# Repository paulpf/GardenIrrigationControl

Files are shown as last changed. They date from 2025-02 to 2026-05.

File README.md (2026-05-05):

# GardenIrrigationControl

> Das Projekt befindet sich noch im Aufbau.

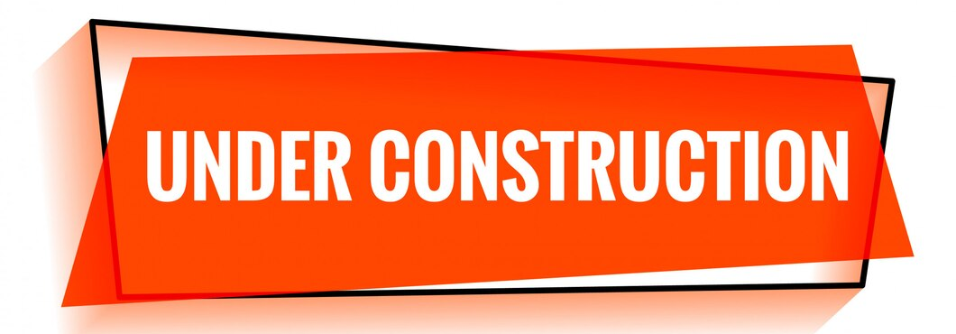
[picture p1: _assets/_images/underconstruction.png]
Projekt im Aufbau


## Inhaltsverzeichnis

- [Projektziel](#projektziel)
- [Anforderungen](#anforderungen)
- [Entwicklungsumgebung](#entwicklungsumgebung)
- [Hardware](#hardware)
  - [Stueckliste](#stueckliste)
  - [ESP32 Dev Kit C V4](#esp32-dev-kit-c-v4)
  - [SSR-Relaismodul](#ssr-relaismodul)
  - [Hunter PGV-101 Ventile](#hunter-pgv-101-ventile)
- [Verschaltung](#verschaltung)
  - [Systemuebersicht](#systemuebersicht)
  - [Steckplatinenansicht](#steckplatinenansicht)
  - [Spannungsversorgung](#spannungsversorgung)
  - [SSR-Modul und Ventile](#ssr-modul-und-ventile)
  - [Taster](#taster)
  - [Status-LED je Zone](#status-led-je-zone)
  - [Wasserstandssensor mit Shunt-Widerstand](#wasserstandssensor-mit-shunt-widerstand)
- [GPIO-Belegung](#gpio-belegung)
  - [Zonenbelegung](#zonenbelegung)
  - [Reservierte und gemiedene Pins](#reservierte-und-gemiedene-pins)
- [Hardware-Risiken und Hinweise](#hardware-risiken-und-hinweise)
- [Hardwaretests](#hardwaretests)
- [OTA-Updates](#ota-updates)

## Projektziel

GardenIrrigationControl steuert eine Gartenbewaesserung mit einem ESP32, einem
SSR-Relaismodul und 24-V-AC-Magnetventilen. Die Bewaesserungszonen koennen per
MQTT, Web-/Netzwerklogik oder ueber physische Taster geschaltet werden. Zusaetzlich
kann der Fuellstand einer Zisterne ueber einen 4-20-mA-Sensor erfasst werden.

## Anforderungen

Das System soll:

- ueber eine Web- bzw. Netzwerk-Schnittstelle steuerbar sein
- Befehle und Statusdaten per MQTT verarbeiten
- physische Taster fuer manuelle Bewaesserung unterstuetzen
- auch ohne WLAN manuell bedienbar bleiben
- den Wasserstand einer Zisterne ueber einen kapazitiven 4-20-mA-Sensor messen
- Over-The-Air-Updates fuer die Firmware unterstuetzen

## Entwicklungsumgebung

Dieses Projekt erwartet Secret- und Konfigurations-Header ausserhalb des
Repositorys.

Setup-Skript ausfuehren:

```powershell
powershell -ExecutionPolicy Bypass -File .\scripts\setup_secrets.ps1
```

Oder unter Windows:

```bat
scripts\setup_secrets.bat
```

Das Skript erstellt oder aktualisiert diese Dateien einen Ordner oberhalb des
Repository-Roots:

- `_secrets/WifiSecret.h`
- `_secrets/MqttSecret.h`
- `_secrets/OtaSecret.h`
- `_config/MqttConfig.h`

Existierende Dateien werden vorher mit Zeitstempel gesichert, z. B.
`WifiSecret.h.20260503-153000.bak`.

## Hardware

### Stueckliste

| Menge | Bauteil | Modell / Wert | Zweck / Hinweis |
| ---: | --- | --- | --- |
| 1 | Microcontroller | ESP32 Dev Kit C V4, AZ-Delivery | Steuerung, WLAN, MQTT, OTA |
| 1 | Relaismodul | 8-Kanal SSR 5 V DC, Low-Level-Trigger | Schaltet Zone 1 bis 8 |
| 1 | Zusatzrelais | 24 V AC geeignet, Low-Level-Trigger | Schaltet Zone 9 / Drainage |
| 9 | Magnetventil | Hunter PGV-101 | 24-V-AC-Bewaesserungsventile |
| 9 | Drucktaster | NO, normally open | Manuelle Zonensteuerung |
| 1 | Trafo | 24 V AC, ausreichend dimensioniert | Versorgung der Magnetventile |
| 1 | Hutschienennetzteil | Mean Well HDR-15-5, 5 V DC | Versorgung von ESP32 und SSR-Steuerseite |
| 1 | 4-20-mA-Sensor | kapazitiver Fuellstandssensor | Zisternenfuellstand |
| 1 | Shunt-Widerstand | ca. 165 Ohm | Wandelt 4-20 mA auf ADC-Spannung |
| 3 | Pull-down-Widerstand | 10 kOhm | Fuer GPIO 34, 35 und 39 |
| optional 9 | Pull-up-Widerstand | 10 kOhm | Je SSR-Eingang nach 3V3, wenn noetig |
| optional 9 | Status-LED | 5 mm, Farbe nach Wunsch | Anzeige des echten 24-V-AC-Ausgangs |
| optional 9 | LED-Vorwiderstand | 10 kOhm / 0,5 W | Strombegrenzung fuer 24 V AC |
| optional 9 | Schutzdiode | 1N4148 oder 1N4007 | Antiparallel zur Status-LED |
| optional 9 | LED-Halter | 5-mm-Frontclip | Montage in der Gehaeusefront |
| optional | Schrumpfschlauch / Litze | 0,14-0,25 mm2 | Isolation und Verdrahtung |

### ESP32 Dev Kit C V4

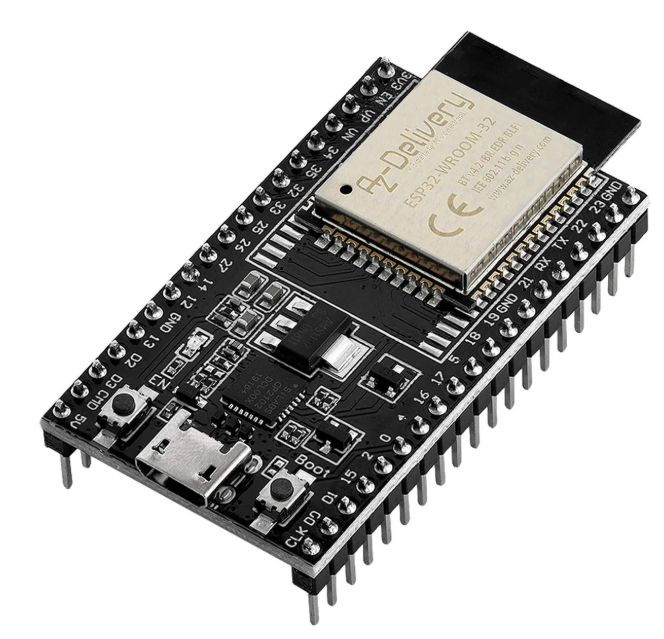
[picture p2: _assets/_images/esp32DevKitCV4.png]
ESP32 Dev Kit C V4


- Produkt: ESP32 Dev Kit C V4
- Anbieter: AZ-Delivery
- Versorgung: 5 V ueber USB oder VIN/5V-Pin, intern 3,3 V Logikpegel

Pinout:

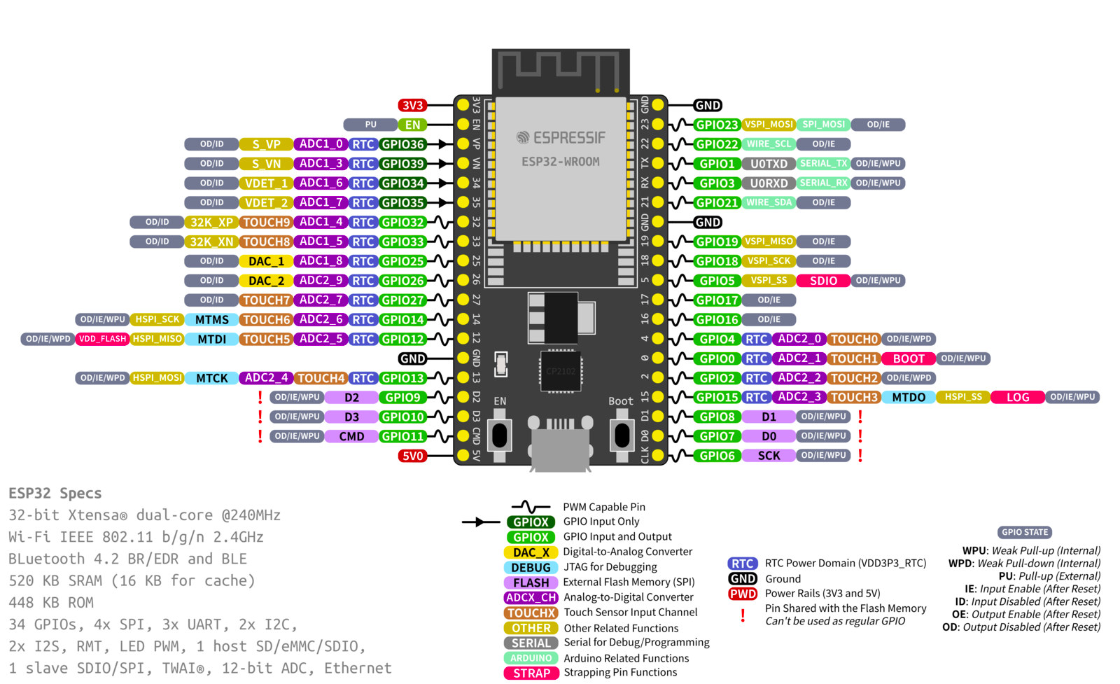
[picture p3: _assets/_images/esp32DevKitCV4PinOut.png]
ESP32 Pinout


Quelle: [ESP32 Pinout](https://www.cnx-software.com/wp-content/uploads/2022/09/ESP32-DevkitC-V4-pinout-diagram.jpg)

### SSR-Relaismodul

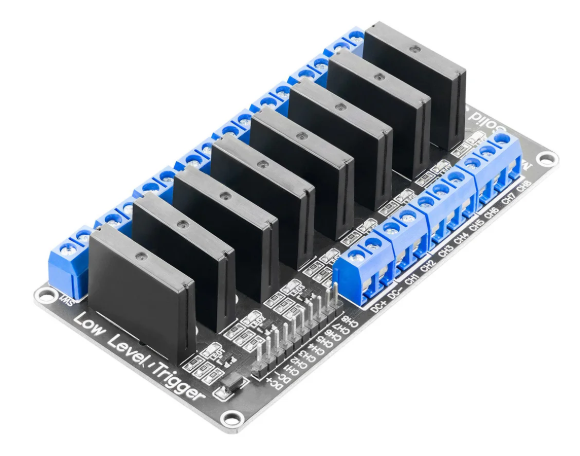
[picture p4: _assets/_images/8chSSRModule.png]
8-Kanal SSR-Modul


- Produkt: 8-Kanal Solid State Relais, 5 V DC, Low-Level-Trigger
- Anbieter: AZ-Delivery
- Steuerseite: 5 V DC
- Lastseite: 24 V AC fuer Magnetventile

Wichtig: LOW am SSR-Eingang aktiviert den Kanal, HIGH deaktiviert ihn.

### Hunter PGV-101 Ventile

- 9 Magnetventile fuer die Bewaesserungszonen
- Betrieb mit 24 V AC
- Zone 9 ist als Zusatz- bzw. Drainagezone vorgesehen

## Verschaltung

### Systemuebersicht

```mermaid
graph TD
    subgraph PSU ["Stromversorgung"]
        V24["24 V AC Trafo"]
        V5["5 V DC Netzteil\nMean Well HDR-15-5"]
    end

    subgraph CTRL ["Steuerung"]
        ESP32["ESP32 Dev Kit C V4"]
    end

    subgraph IO ["Eingabe"]
        BTN["9x Drucktaster\nNO, gegen 3V3"]
        SENSOR["4-20-mA-Fuellstandssensor\nueber Shunt an GPIO36 / VP"]
    end

    subgraph REL ["Relais"]
        SSR["8-Kanal SSR Modul\n+ 1 Zusatzrelais\nLOW = aktiv"]
    end

    subgraph VALVES ["Bewaesserungsventile"]
        V1["Zone 1"]
        V2["Zone 2"]
        V3["Zone 3"]
        V4["Zone 4"]
        V5X["Zone 5"]
        V6["Zone 6"]
        V7["Zone 7"]
        V8["Zone 8"]
        V9["Zone 9 Drainage"]
    end

    V5 -->|"5 V DC"| ESP32
    V5 -->|"5 V DC Steuerseite"| SSR
    ESP32 -->|"GPIO 16,17,18,19,21,22,23,25,26"| SSR
    BTN -->|"GPIO 4,13,14,27,32,33,34,35,39"| ESP32
    SENSOR -->|"ADC GPIO36 / VP"| ESP32
    V24 -->|"24 V AC gemeinsame Leitung"| SSR
    SSR -->|"24 V AC geschaltet"| V1 & V2 & V3 & V4 & V5X & V6 & V7 & V8 & V9
    V24 -->|"24 V AC Rueckleitung"| V1 & V2 & V3 & V4 & V5X & V6 & V7 & V8 & V9
```

Fallback-Grafik ohne Mermaid-Renderer:
[docs/system_overview.svg](docs/system_overview.svg)

### Steckplatinenansicht

<figure>
  Fritzing-Steckplatinenansicht der GardenIrrigationControl-Verdrahtung
  <figcaption>Steckplatinenansicht der ESP32-, SSR-, Taster- und Ventilverdrahtung.</figcaption>
</figure>

Die Grafik ist aus der Fritzing-Datei `_assets/IrrigationCircuit.fzz`
abgeleitet und dient als visuelle Aufbauhilfe zur nachfolgenden
Verdrahtungsbeschreibung.

### Spannungsversorgung

```text
Steckdose 230 V AC
|
+-- 24 V AC Trafo
|   +-- L1 -> SSR COM / gemeinsame Eingangsleitung
|   +-- L2 -> gemeinsame Rueckleitung aller Ventile
|
+-- 5 V DC Netzteil Mean Well HDR-15-5
    +-- +V -> ESP32 VIN/5V
    +-- 5 V -> SSR VCC / Steuerseite
    +-- -V/GND -> ESP32 GND und SSR GND
```

Wichtig: ESP32-GND und SSR-Steuer-GND muessen verbunden sein. Die 24-V-AC-Seite
bleibt galvanisch von der Steuerseite getrennt.

Das ESP32 Dev Kit C V4 wird mit 5 V am VIN/5V-Pin versorgt. Der
Spannungsregler auf dem Devboard erzeugt daraus die interne 3,3-V-Versorgung
fuer den ESP32 und kleine 3,3-V-Verbraucher. Niemals 5 V direkt an einen
3V3-Pin anschliessen. Bei gleichzeitiger USB-Verbindung zum PC pruefen, ob das
konkrete Devboard eine Rueckspeisung zwischen externer 5-V-Versorgung und USB
verhindert.

### SSR-Modul und Ventile

Verdrahtung je Zone:

```text
ESP32 GPIO, z. B. GPIO16 -----------------> SSR IN1
ESP32 GND --------------------------------> SSR GND
5 V DC -----------------------------------> SSR VCC

24 V AC Trafo L1 -------------------------> SSR COM
SSR NO / Ausgang -------------------------> Ventil Zone 1, Klemme A
24 V AC Trafo L2 -------------------------> Ventil Zone 1, Klemme B
```

Vereinfachter Stromkreis:

```text
24 V AC L1 -- SSR COM -- SSR Ausgang -- Ventil -- 24 V AC L2
```

Bei LOW am Relais-GPIO schliesst der SSR-Kanal und das Ventil oeffnet. Bei HIGH
ist der Kanal aus und das Ventil geschlossen. Die Firmware setzt die Relaispins
beim Start zuerst auf HIGH und schaltet sie danach als OUTPUT, damit die
Ausgaenge moeglichst inaktiv starten.

### Taster

Jeder Taster ist als normally-open-Taster gegen 3V3 verdrahtet:

```text
3V3 ---- Taster ---- ESP32 GPIO
GND ---- Pull-down -- ESP32 GPIO
```

Fuer GPIO 4, 13, 14, 27, 32 und 33 wird der interne Pull-down des ESP32 genutzt.
GPIO 34, 35 und 39 sind input-only und besitzen keinen internen Pull-down; diese
drei Taster benoetigen jeweils einen externen 10-kOhm-Pull-down nach GND.

### Status-LED je Zone

Wenn eine LED den realen Schaltzustand anzeigen soll, wird sie parallel zum
jeweiligen 24-V-AC-Ventilausgang angeschlossen. Dadurch zeigt sie den tatsaechlich
geschalteten Ausgang, nicht nur den GPIO-Zustand.

<figure>
  24 V AC Status-LED mit 10 kOhm Vorwiderstand und antiparalleler Schutzdiode
  <figcaption>24 V AC Status-LED mit Vorwiderstand R1 und antiparalleler Schutzdiode D1.</figcaption>
</figure>

Stueckliste pro LED:

| Menge | Bauteil | Wert / Typ | Hinweis |
| ---: | --- | --- | --- |
| 1 | LED | 5 mm, Farbe nach Wunsch | Lange Anschlussfahne ist meist Anode |
| 1 | Widerstand R1 | 10 kOhm / 0,5 W | 0,25 W reicht rechnerisch, 0,5 W ist robuster |
| 1 | Diode D1 | 1N4148 oder 1N4007 | Ring / Strich markiert die Kathode |
| 1 | LED-Halter | 5-mm-Frontclip | Passend zur Gehaeusefront |
| 1 | Schrumpfschlauch | passend | Alle blanken Kontakte isolieren |
| optional | Litze | 0,14-0,25 mm2 | Anschluss an Klemme oder Platine |

Verdrahtung:

1. R1 in Reihe zur LED einbauen.
2. D1 direkt antiparallel zur LED anschliessen.
3. Dioden-Kathode, also Ring / Strich, an die LED-Anode anschliessen.
4. Dioden-Anode an die LED-Kathode anschliessen.
5. LED-Schaltung parallel zum jeweiligen 24-V-AC-Ventilausgang anschliessen.
6. Alle blanken Anschluesse mit Schrumpfschlauch isolieren.

Dimensionierung:

```text
24 V AC * 1,414 = ca. 34 V Spitzenspannung
I = (34 V - ca. 2 V) / 10000 Ohm = ca. 3,2 mA Spitzenstrom
P = 24 V * 24 V / 10000 Ohm = ca. 0,058 W
```

Ein 0,25-W-Widerstand reicht rechnerisch aus. Ein 0,5-W-Widerstand ist
empfehlenswert, weil er kuehler bleibt, mechanisch robuster ist und mehr Reserve
im Gehaeuse bietet.

### Wasserstandssensor mit Shunt-Widerstand

Der Wasserstandssensor liefert ein 4-20-mA-Signal. Der ESP32 misst aber keine
Stroeme direkt, sondern eine Spannung am ADC. Deshalb wird der Sensorstrom durch
einen Shunt-Widerstand gefuehrt. Die Spannung ueber diesem Widerstand liegt am
ADC-Pin GPIO36 / VP an.

<figure>
  4-20 mA Wasserstandssensor mit 165 Ohm Shunt-Widerstand an ESP32 GPIO36 VP
  <figcaption>4-20-mA-Sensor mit 165-Ohm-Shunt am ADC-Eingang GPIO36 / VP.</figcaption>
</figure>

Stueckliste fuer den Messeingang:

| Menge | Bauteil | Wert / Typ | Hinweis |
| ---: | --- | --- | --- |
| 1 | Fuellstandssensor | 4-20 mA, kapazitiv | Versorgung laut Sensor-Datenblatt |
| 1 | Shunt-Widerstand | ca. 165 Ohm | Wandelt 4-20 mA in ca. 0,66-3,3 V |
| optional 1 | Serienwiderstand | 1 kOhm | Zusaetzlicher Schutz vor dem ADC-Pin |
| optional 1 | Kondensator | 100 nF | Gegen GND am ADC-Knoten zur Glaettung |

Verdrahtung bei einem typischen 2-Draht-4-20-mA-Sensor:

```text
DC Versorgung + ---- Sensor + 
Sensor - / Iout ---- ADC-Knoten ---- GPIO36 / VP
ADC-Knoten --------- Rshunt 165 Ohm ---- GND
DC Versorgung GND ---------------------- GND
ESP32 GND ------------------------------ GND
```

Der ADC-Knoten ist die Verbindung aus Sensor-Ausgang, Shunt-Widerstand und
GPIO36 / VP. Der Shunt liegt von diesem Knoten nach GND. ESP32-GND und die
Masse der Sensorspeisung muessen verbunden sein, damit der ADC eine definierte
Bezugsspannung hat.

Dimensionierung:

```text
U = I * R
Umin = 0,004 A * 165 Ohm = 0,66 V
Umax = 0,020 A * 165 Ohm = 3,30 V
Pmax = I^2 * R = 0,020 A * 0,020 A * 165 Ohm = 0,066 W
```

Ein 0,25-W-Widerstand reicht elektrisch aus; 0,5 W ist mechanisch robuster. Der
ADC-Pin GPIO36 / VP darf maximal 3,3 V sehen. Daher darf die Sensorversorgung
niemals direkt auf GPIO36 gelegt werden, und 24 V AC gehoert ausschliesslich auf
die Ventilseite, nicht auf den Messeingang.

Firmware-Bezug:

| Firmware-Wert | Bedeutung |
| --- | --- |
| `WATER_LEVEL_SENSOR_PIN = 36` | ADC-Eingang GPIO36 / VP |
| `WATER_LEVEL_ADC_MIN = 820` | ca. 0,66 V bei 4 mA |
| `WATER_LEVEL_ADC_MAX = 4095` | ca. 3,3 V bei 20 mA |

## GPIO-Belegung

### Zonenbelegung

Diese Tabelle entspricht der Firmware in `src/config/config.h`.

| Zone | Funktion | Taster-GPIO | Taster-Board-Label | Relais-GPIO | Relais-Board-Label | SSR-Kanal | Hinweis |
| --- | --- | ---: | --- | ---: | --- | --- | --- |
| 1 | Bewaesserung | 4 | D4 | 16 | RX2 | IN1 | interner Pull-down |
| 2 | Bewaesserung | 13 | D13 | 17 | TX2 | IN2 | interner Pull-down |
| 3 | Bewaesserung | 14 | D14 | 18 | D18 | IN3 | interner Pull-down |
| 4 | Bewaesserung | 27 | D27 | 19 | D19 | IN4 | interner Pull-down |
| 5 | Bewaesserung | 32 | D32 | 21 | D21 | IN5 | interner Pull-down |
| 6 | Bewaesserung | 33 | D33 | 22 | D22 | IN6 | interner Pull-down |
| 7 | Bewaesserung | 34 | D34 | 23 | D23 | IN7 | externer 10-kOhm-Pull-down noetig |
| 8 | Bewaesserung | 35 | D35 | 25 | D25 | IN8 | externer 10-kOhm-Pull-down noetig |
| 9 | Drainage / Zusatzventil | 39 | VN | 26 | D26 | Zusatzrelais | externer 10-kOhm-Pull-down noetig |

Weitere Sensorik:

| Funktion | GPIO | Board-Label | Hinweis |
| --- | ---: | --- | --- |
| Wasserstand 4-20 mA | 36 | VP | ADC1, ueber Shunt-Widerstand |

ADC-Vorgaben in der Firmware:

| Wert | Bedeutung |
| --- | --- |
| `WATER_LEVEL_ADC_MIN = 820` | ca. 0,66 V bei 4 mA an 165 Ohm |
| `WATER_LEVEL_ADC_MAX = 4095` | ca. 3,3 V bei 20 mA an 165 Ohm |

### Reservierte und gemiedene Pins

| GPIO | Grund |
| --- | --- |
| 0, 2, 5, 12, 15 | Strapping-Pins, bleiben frei |
| 1, 3 | UART TX/RX fuer Serial / OTA |
| 6 bis 11 | ESP32-Flash, nicht verwenden |
| 34, 35, 39 | input-only, kein interner Pull-down |
| 36 / VP | input-only, fuer Wasserstandssensor reserviert |

## Hardware-Risiken und Hinweise

| Problem | Status / Risiko | Empfehlung |
| --- | --- | --- |
| 8-Kanal-SSR reicht nur fuer 8 Zonen | geloest | Zone 9 nutzt ein separates Zusatzrelais |
| LOW-active SSR-Eingaenge koennen beim Reset floaten | niedrig | Firmware startet Relaispins inaktiv; optional 10-kOhm-Pull-up je SSR-Eingang pruefen |
| Hunter PGV-101 benoetigt 24 V AC | geloest | 24-V-AC-Trafo und AC-faehige Relais-/SSR-Lastseite verwenden |
| Kurzschluss / Ueberstrom auf Ventilseite | mittel | Feinsicherung 1 A pro Ventilkreis oder Gruppenabsicherung vorsehen |
| GPIO 34, 35 und 39 ohne Pull-down | relevant | Je Taster einen externen 10-kOhm-Pull-down nach GND verbauen |

## Hardwaretests

Der Test `test_embedded_esp32_gpio_io` laeuft direkt auf dem per USB
angeschlossenen ESP32 und prueft die GPIOs:

- Ausgangs-GPIOs werden kurz auf LOW und HIGH gesetzt und per `digitalRead()`
  zurueckgelesen.
- Eingangs-GPIOs muessen im Ruhezustand LOW sein.
- Fuer jeden Eingang fordert der Test im Terminal auf, den Eingang kurz auf HIGH
  zu bringen und danach wieder loszulassen.

Sicherheit vor dem Test: Der Test schaltet die Ausgangs-GPIOs kurz auf LOW. Wenn
das SSR-Modul angeschlossen ist, kann dadurch ein Relais aktivieren. Fuer einen
reinen ESP32-Test daher SSR-Modul oder Ventilversorgung trennen.

Ausfuehren:

```powershell
pio test -e az-delivery-devkit-v4-usb -f test_embedded_esp32_gpio_io
```

Falls `pio` in der aktuellen Shell nicht im `PATH` liegt:

```powershell
C:\Users\paul\.platformio\penv\Scripts\pio.exe test -e az-delivery-devkit-v4-usb -f test_embedded_esp32_gpio_io
```

Ein erfolgreicher Lauf endet mit `PASSED`.

## OTA-Updates

Dieses Projekt unterstuetzt OTA-Updates, damit neue Firmware ohne direkten
USB-Zugriff auf den ESP32 geladen werden kann.

1. IP-Adresse des ESP32 ermitteln, z. B. im Router oder ueber den Serial Monitor.
2. In `platformio.ini` im Environment fuer OTA den Upload-Port setzen:

   ```ini
   upload_port = 192.168.x.x
   ```

3. In `OtaSecret.h` das OTA-Passwort setzen:

   ```cpp
   #define OTA_PASSWORD "YourSecurePassword123"
   ```

4. Firmware hochladen:

   ```bash
   pio run -e esp32dev-ota -t upload
   ```

Bei Timeout-Problemen kann in `platformio.ini` ein groesserer Timeout gesetzt
werden:

```ini
upload_flags =
  --port=3232
  --timeout=30
```

Waehrend eines OTA-Updates pausiert das System Bewaesserungsoperationen, damit
das Update stabil durchlaufen kann.

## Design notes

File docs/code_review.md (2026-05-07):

# Code Review

Datum: 2026-05-07
Repository: GardenIrrigationControl

## Kurzfazit

Das Projekt ist fuer ein Embedded-/ESP32-Projekt bereits gut strukturiert. Die
Trennung in `app`, `domain`, `infrastructure`, `services`, `contracts` und
Tests ist ein solider Anfang. Besonders positiv sind die Native-Tests, die
Dependency-Injection-Ansaetze und die Dokumentation der Hardware.

Die wichtigsten Verbesserungsfelder liegen bei langlebiger ESP32-Stabilitaet,
MQTT-Verantwortlichkeiten, echter Produktionslogik in Tests und dem Umgang mit
noch unfertigen Features.

## Testergebnis

Native-Testlauf:

```text
pio test -e native
127 test cases: 127 succeeded
```

Hinweis: Der erste Testlauf im Sandbox-Kontext scheiterte an PlatformIO-
Berechtigungen unter `C:\Users\ppfei\.platformio`. Nach Ausfuehrung ausserhalb
der Sandbox liefen alle Native-Tests erfolgreich.

## Findings

### 1. Geplante Bewaesserung ist noch nicht funktionsfaehig

Datei: `src/domain/scheduled_irrigation.cpp`

`ScheduledIrrigation::isScheduleTimeMatch()` gibt aktuell immer `false`
zurueck. Dadurch kann geplante Bewaesserung nie ausloesen, obwohl Klasse und
Tests bereits wie ein vorhandenes Feature wirken.

Empfehlung:

- Entweder das Feature klar als unfertig kennzeichnen und nicht als fertige
  Funktion behandeln.
- Oder einen echten Zeitprovider/NTP-Provider integrieren und
  `isScheduleTimeMatch()` produktionsreif implementieren.
- Tests sollten danach echte Trigger-Faelle gegen Produktionslogik abdecken.

### 2. MQTT-Payloads werden still auf 255 Zeichen gekuerzt

Datei: `src/infrastructure/mqttmanager.cpp`

In `instanceMqttCallback()` wird der Payload in einen festen Buffer kopiert.
Payloads ueber 255 Zeichen werden abgeschnitten, ohne dass der Command
abgelehnt oder als fehlerhaft markiert wird.

Fuer aktuelle Bool- und Duration-Kommandos ist das meist unkritisch. Sobald
spaeter JSON-Kommandos, Schedule-Konfigurationen oder komplexere Payloads per
MQTT kommen, kann daraus aber ein schwer zu findender Fehler entstehen.

Empfehlung:

- Ueberlange Payloads explizit erkennen.
- Command mit Logmeldung ablehnen statt gekuerzt weiterzuverarbeiten.
- Fuer kuenftige JSON-Kommandos feste Maximalgroessen definieren.

### 3. Viele temporaere `String`-Objekte im MQTT-Hotpath

Dateien:

- `src/infrastructure/mqttmanager.cpp`
- `src/infrastructure/mqttmanager.h`

Der MQTT-Callback erzeugt viele temporaere `String`-Objekte fuer Topic-Vergleiche,
Topic-Erzeugung, Logs und Publish-Payloads. Auf ESP32-Systemen kann das bei
langer Laufzeit Heap-Fragmentierung beguenstigen.

Empfehlung:

- MQTT-Topics beim Setup einmal in feste Buffer vorberechnen.
- Eine kleine `MqttTopicRegistry` oder einen `MqttTopicBuilder` einfuehren.
- Im Callback moeglichst mit `strcmp`, Prefix-Matching und festen Buffern
  arbeiten.
- `String` in seltenen Setup-/Logpfaden tolerieren, aber nicht im Hotpath.

### 4. ISR- und Mainloop-Zugriff sind nur mit `volatile` abgesichert

Dateien:

- `src/domain/irrigation_zone.cpp`
- `src/domain/irrigation_zone.h`

`_lastDebounceTime` und `_buttonEventPending` werden aus Interrupt-Service-
Routine und Mainloop genutzt. `volatile` verhindert Optimierungen, ist aber
keine vollstaendige Synchronisation.

Empfehlung:

- ISR minimal halten und nur ein Ereignis-Flag setzen.
- Debounce-Logik vollstaendig in der Mainloop ausfuehren.
- Alternativ kritische Abschnitte fuer gemeinsam genutzte Werte verwenden.
- Ggf. einen kleinen `ButtonDebouncer` als testbare Domain-Komponente
  extrahieren.

### 5. Wasserstand-Prozentwert wird unten begrenzt, aber nicht oben

Datei: `src/domain/waterlevelmanager.cpp`

Der berechnete Prozentwert wird auf mindestens 0 begrenzt, aber nicht auf 100.
Das ist fuer Overflow-Erkennung teilweise sinnvoll, vermischt aber Anzeige- und
Diagnosewert.

Empfehlung:

- Zwei Werte unterscheiden:
  - `rawPercent` fuer Diagnose, Sensorfehler und Overflow-Erkennung.
  - `displayPercent` fuer UI/MQTT-Anzeige, begrenzt auf `0..100`.
- MQTT-Topics entsprechend klar benennen oder dokumentieren.

### 6. OTA ist als Default-Environment aktiviert

Datei: `platformio.ini`

`default_envs` enthaelt USB und OTA. Gleichzeitig steht im OTA-Environment eine
konkrete IP-Adresse sowie ein Platzhalter fuer das Auth-Flag.

Risiko:

- Versehentliche OTA-Builds oder Uploads.
- Lokale IP-Adresse im versionierten Projekt.
- Auth-Konfiguration wirkt wie ein Platzhalter, ist aber Teil der aktiven
  Projektkonfiguration.

Empfehlung:

- OTA aus `default_envs` entfernen.
- OTA-Upload nur bewusst mit `pio run -e az-delivery-devkit-v4-ota -t upload`
  starten.
- IP/Auth aus lokaler Konfiguration oder Secrets beziehen.
- Beispielwerte in eine dokumentierte Template-Datei verschieben.

## Design-Tipps

### MQTT-Verantwortlichkeiten aufteilen

`MqttManager` uebernimmt derzeit viele Aufgaben:

- MQTT-Verbindung
- Reconnect-Logik
- Topic-Erzeugung
- Command-Parsing
- Factory-Reset
- Duration-Reset
- State-Publishing
- LWT/Systemstatus

Empfohlene Aufteilung:

- `MqttConnectionManager` fuer Verbindung und Reconnect.
- `MqttTopicBuilder` oder `MqttTopicRegistry` fuer Topics.
- `IrrigationCommandHandler` fuer Zonen-Kommandos.
- `SystemCommandHandler` fuer Reset/Systembefehle.
- `MqttStatePublisher` fuer Status- und Sensor-Publishes.

Das macht die Klasse kleiner, reduziert Kopplung und erleichtert gezielte Tests.

### Domain weiter von Infrastruktur trennen

Die Richtung mit `contracts/` ist gut. Einige Domain-Klassen greifen aber noch
direkt auf Infrastruktur zu, zum Beispiel `IrrigationZone` auf
`StorageManager::getInstance()`.

Empfehlung:

- Interface wie `IZoneSettingsStore` einfuehren.
- Storage ueber Konstruktor oder Setup injizieren.
- Domain-Logik ohne NVS/Preferences testbar machen.

### Tests naeher an Produktionslogik bringen

Einige Tests kopieren Produktionslogik oder testen eher Checklisten als echtes
Verhalten. Dadurch koennen Tests gruen sein, obwohl sich die echte
Implementierung anders verhaelt.

Empfehlung:

- Reine Funktionen aus Produktionscode extrahieren und direkt testen.
- Kopierte Test-Hilfsfunktionen schrittweise entfernen.
- Checklist-/Dokumentations-Tests in echte Verhaltens-Tests umwandeln.
- Scheduled-Irrigation-Tests erst dann als Feature-Test werten, wenn die
  Zeitlogik wirklich implementiert ist.

### Einheitliche Sprache und Benennung

Im Code sind Begriffe wie `relais` und `relay` gemischt. Dazu kommen deutsche
und englische Kommentare bzw. Bezeichner.

Empfehlung:

- Code-Bezeichner einheitlich auf Englisch halten.
- Hardware-Dokumentation im README kann weiterhin Deutsch bleiben.
- Begriffe wie `durationTime` praezisieren, zum Beispiel `durationMs` oder
  `durationSeconds`.

### Konfiguration klarer schichten

Aktuell liegen Defaults, Hardware-Pins, Wasserlevel-Konfiguration, OTA-Schalter
und Timing-Werte eng zusammen.

Empfehlung:

- Hardware-Pins in `hardwareconfig`.
- Laufzeit-/Loop-Parameter in `systemconfig`.
- Sensorwerte in `waterlevelconfig`.
- MQTT-/OTA-/WiFi-Werte konsequent ueber lokale Secrets oder Templates.
- README mit einer kurzen Konfigurationsmatrix ergaenzen.

## Positives

- Gute Native-Testbasis mit erfolgreichem Testlauf.
- Klare Projektstruktur mit begonnener Schichtenarchitektur.
- Hardware-Dokumentation ist ausfuehrlich und praxisnah.
- Relais-Startzustand wird fuer LOW-active Ausgaenge bewusst abgesichert.
- MQTT-LWT und Systemstatus zeigen, dass Produktionsbetrieb mitgedacht wurde.
- Wasserstand-Logik nutzt Hysterese und trennt Sensorlesen, Transitionen und
  Publishing schon recht sauber.

## Priorisierte naechste Schritte

1. `ScheduledIrrigation` entweder fertig implementieren oder klar deaktivieren.
2. MQTT-Payload-Laengen validieren und ueberlange Nachrichten ablehnen.
3. OTA aus den Default-Environments entfernen.
4. ISR-/Button-Debounce robuster gestalten.
5. MQTT-Topic-Erzeugung aus dem Hotpath herausziehen.
6. Tests bereinigen, die Produktionslogik kopieren statt sie zu testen.
7. Storage-Abhaengigkeit aus der Domain ueber ein Interface entkoppeln.

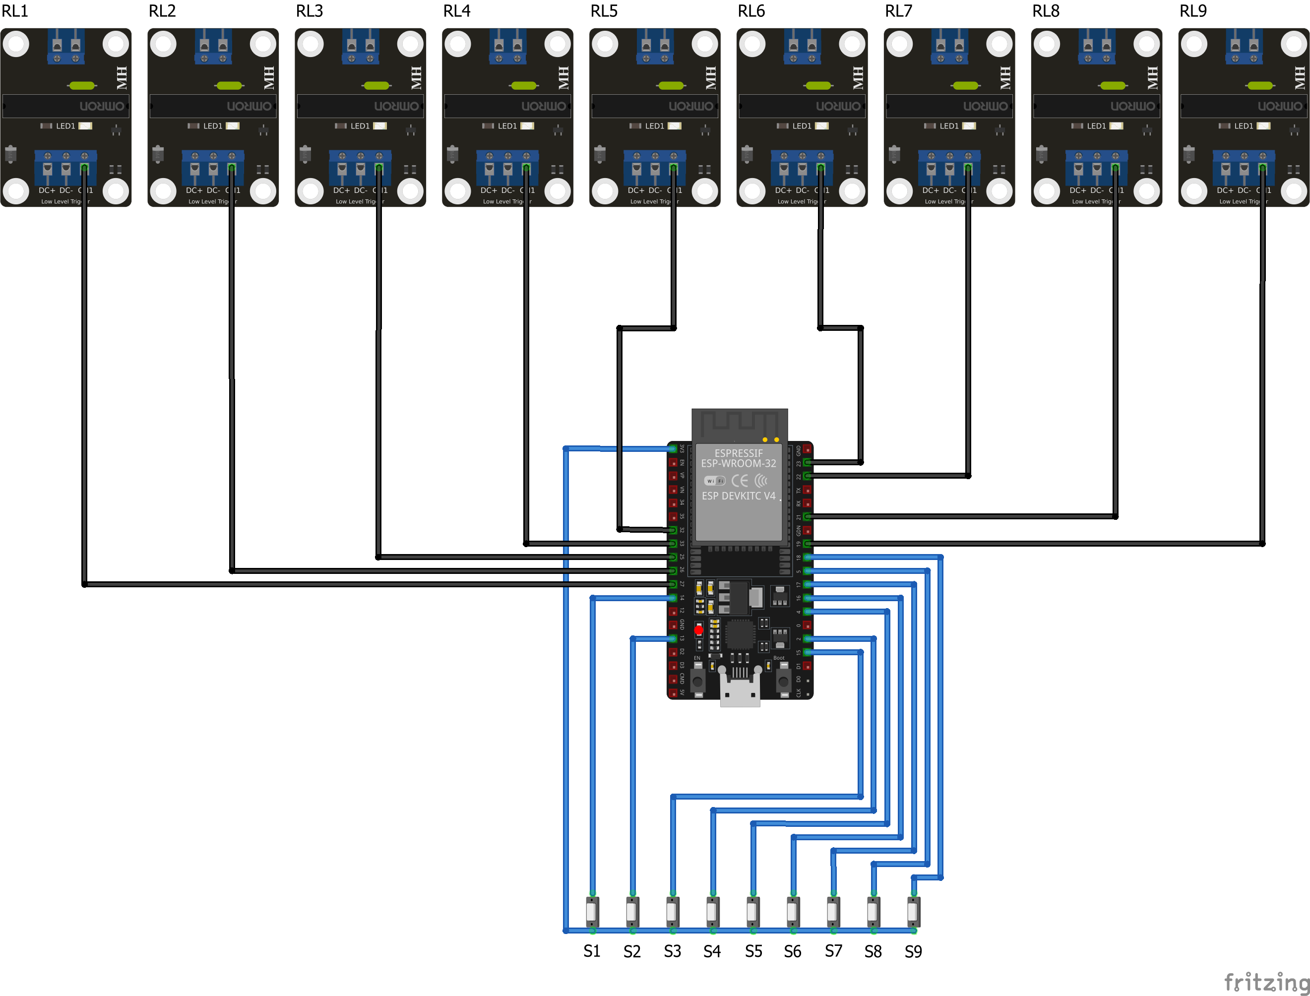
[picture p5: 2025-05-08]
_assets/_images/IrrigationCircuit_Steckplatine.png

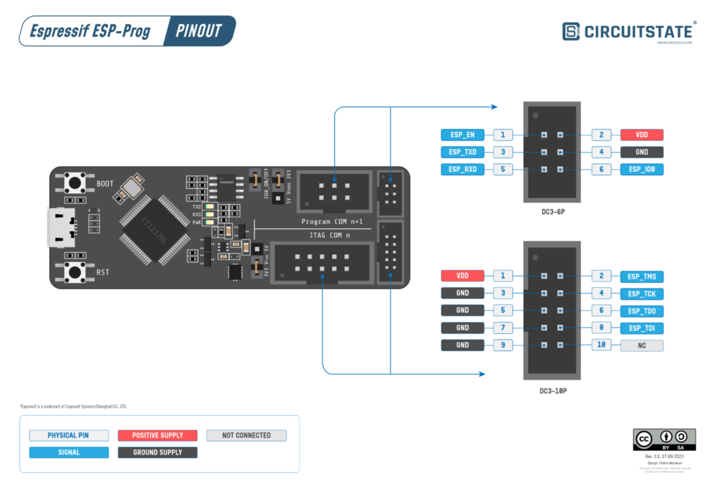
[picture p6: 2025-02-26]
_assets/_images/espprog.png

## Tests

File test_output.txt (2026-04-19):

Verbosity level can be increased via `-v, -vv, or -vvv` option
Collected 5 tests

Processing test_native_duration_formatter in native environment
--------------------------------------------------------------------------------
Building...
Testing...
test\test_native_duration_formatter\test_main.cpp:132: test_arduino_string_basic	[PASSED]
test\test_native_duration_formatter\test_main.cpp:133: test_arduino_string_int_conversion	[PASSED]
test\test_native_duration_formatter\test_main.cpp:134: test_arduino_string_concat	[PASSED]
test\test_native_duration_formatter\test_main.cpp:137: test_format_zero_returns_zeros	[PASSED]
test\test_native_duration_formatter\test_main.cpp:138: test_format_negative_returns_zeros	[PASSED]
test\test_native_duration_formatter\test_main.cpp:139: test_format_double_digit_seconds	[PASSED]
test\test_native_duration_formatter\test_main.cpp:140: test_format_exactly_one_minute	[PASSED]
test\test_native_duration_formatter\test_main.cpp:141: test_current_impl_has_seconds_suffix_bug	[PASSED]
test\test_native_duration_formatter\test_main.cpp:142: test_fixed_impl_single_digit_seconds	[PASSED]
test\test_native_duration_formatter\test_main.cpp:143: test_fixed_impl_one_second	[PASSED]
test\test_native_duration_formatter\test_main.cpp:144: test_fixed_impl_nine_seconds	[PASSED]
test\test_native_duration_formatter\test_main.cpp:145: test_fixed_impl_ten_seconds	[PASSED]
test\test_native_duration_formatter\test_main.cpp:146: test_format_large_duration	[PASSED]
------- native:test_native_duration_formatter [PASSED] Took 3.84 seconds -------

Processing test_native_irrigation_zone in native environment
--------------------------------------------------------------------------------
Building...
Testing...
test\test_native_irrigation_zone\test_main.cpp:153: test_timer_inactive_returns_zero	[PASSED]
test\test_native_irrigation_zone\test_main.cpp:154: test_timer_full_duration	[PASSED]
test\test_native_irrigation_zone\test_main.cpp:155: test_timer_half_elapsed	[PASSED]
test\test_native_irrigation_zone\test_main.cpp:156: test_timer_expired_clamped	[PASSED]
test\test_native_irrigation_zone\test_main.cpp:157: test_timer_large_elapsed_no_underflow	[PASSED]
test\test_native_irrigation_zone\test_main.cpp:158: test_timer_with_offset	[PASSED]
test\test_native_irrigation_zone\test_main.cpp:161: test_format_zero	[PASSED]
test\test_native_irrigation_zone\test_main.cpp:162: test_format_01_03	[PASSED]
test\test_native_irrigation_zone\test_main.cpp:163: test_format_05_00	[PASSED]
test\test_native_irrigation_zone\test_main.cpp:164: test_format_05_30	[PASSED]
test\test_native_irrigation_zone\test_main.cpp:165: test_format_single_digit_seconds	[PASSED]
test\test_native_irrigation_zone\test_main.cpp:166: test_format_00_59	[PASSED]
test\test_native_irrigation_zone\test_main.cpp:167: test_format_60_00	[PASSED]
test\test_native_irrigation_zone\test_main.cpp:168: test_format_negative	[PASSED]
-------- native:test_native_irrigation_zone [PASSED] Took 2.48 seconds --------

Processing test_native_mqtt_lwt in native environment
--------------------------------------------------------------------------------
Building...
Testing...
test\test_native_mqtt_lwt\test_main.cpp:261: test_lwt_offline_payload_string	[PASSED]
test\test_native_mqtt_lwt\test_main.cpp:262: test_lwt_online_payload_string	[PASSED]
test\test_native_mqtt_lwt\test_main.cpp:263: test_lwt_payloads_are_different	[PASSED]
test\test_native_mqtt_lwt\test_main.cpp:266: test_lwt_topic_format_structure	[PASSED]
test\test_native_mqtt_lwt\test_main.cpp:267: test_lwt_topic_with_different_device_names	[PASSED]
test\test_native_mqtt_lwt\test_main.cpp:270: test_lwt_qos_level_1	[PASSED]
test\test_native_mqtt_lwt\test_main.cpp:271: test_lwt_retain_flag_enabled	[PASSED]
test\test_native_mqtt_lwt\test_main.cpp:272: test_lwt_parameters_are_correct	[PASSED]
test\test_native_mqtt_lwt\test_main.cpp:275: test_lwt_prevents_stale_online_status	[PASSED]
test\test_native_mqtt_lwt\test_main.cpp:276: test_lwt_enables_failover_automation	[PASSED]
test\test_native_mqtt_lwt\test_main.cpp:277: test_lwt_improves_reliability	[PASSED]
test\test_native_mqtt_lwt\test_main.cpp:280: test_lwt_topic_buffer_no_overflow_minimal_name	[PASSED]
test\test_native_mqtt_lwt\test_main.cpp:281: test_lwt_topic_buffer_no_overflow_long_name	[PASSED]
test\test_native_mqtt_lwt\test_main.cpp:282: test_lwt_payload_strings_immutable	[PASSED]
test\test_native_mqtt_lwt\test_main.cpp:285: test_phase_5_2_implementation_checklist	[PASSED]
test\test_native_mqtt_lwt\test_main.cpp:286: test_phase_5_2_mqtt_reliability_improvement	[PASSED]
test\test_native_mqtt_lwt\test_main.cpp:287: test_phase_5_2_critical_for_production	[PASSED]
------------ native:test_native_mqtt_lwt [PASSED] Took 2.50 seconds ------------

Processing test_native_mqtt_session_manager in native environment
--------------------------------------------------------------------------------
Building...
Testing...
pio : [WinError 4551] Eine Anwendungssteuerungsrichtlinie hat diese Datei 
blockiert
In Zeile:1 Zeichen:1
+ pio test -e native 2>&1 > test_output.txt; Get-Content test_output.tx ...
+ ~~~~~~~~~~~~~~~~~~~~~~~~~~~~~~~~~~~~~~~~~
    + CategoryInfo          : NotSpecified: ([WinError 4551]...Datei blockiert 
   :String) [], RemoteException
    + FullyQualifiedErrorId : NativeCommandError
 
----- native:test_native_mqtt_session_manager [ERRORED] Took 1.54 seconds -----

Processing test_native_trace_logging in native environment
--------------------------------------------------------------------------------
Building...
Testing...
test\test_native_trace_logging\test_main.cpp:157: test_trace_level_logs_at_trace	[PASSED]
test\test_native_trace_logging\test_main.cpp:158: test_info_not_logged_when_debug_configured	[PASSED]
test\test_native_trace_logging\test_main.cpp:159: test_trace_not_logged_when_debug_configured	[PASSED]
test\test_native_trace_logging\test_main.cpp:160: test_debug_logs_at_debug_level	[PASSED]
test\test_native_trace_logging\test_main.cpp:161: test_error_logs_when_info_configured	[PASSED]
test\test_native_trace_logging\test_main.cpp:164: test_prefix_trace	[PASSED]
test\test_native_trace_logging\test_main.cpp:165: test_prefix_debug	[PASSED]
test\test_native_trace_logging\test_main.cpp:166: test_prefix_info	[PASSED]
test\test_native_trace_logging\test_main.cpp:167: test_prefix_error	[PASSED]
test\test_native_trace_logging\test_main.cpp:168: test_prefix_unknown_defaults_to_log	[PASSED]
test\test_native_trace_logging\test_main.cpp:171: test_all_levels_log_at_trace_level	[PASSED]
test\test_native_trace_logging\test_main.cpp:172: test_only_error_logs_at_error_level	[PASSED]
test\test_native_trace_logging\test_main.cpp:173: test_none_level_blocks_all_logs	[PASSED]
--------- native:test_native_trace_logging [PASSED] Took 2.77 seconds ---------

=================================== SUMMARY ===================================
Environment    Test                              Status    Duration
-------------  --------------------------------  --------  ------------
native         test_native_duration_formatter    PASSED    00:00:03.844
native         test_native_irrigation_zone       PASSED    00:00:02.475
native         test_native_mqtt_lwt              PASSED    00:00:02.503
native         test_native_mqtt_session_manager  ERRORED   00:00:01.539
native         test_native_trace_logging         PASSED    00:00:02.769
================= 58 test cases: 57 succeeded in 00:00:13.130 =================

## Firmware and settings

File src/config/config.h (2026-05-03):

#ifndef CONFIG_H
#define CONFIG_H

// Pins configuration for ESP32
//
// Strapping-Pins (0, 2, 5, 12, 15) bleiben frei.
// GPIO 1, 3: UART TX/RX (Serial/OTA).
// GPIO 6-11: intern fuer Flash reserviert.
// GPIO 34, 35, 39: input-only, externer Pull-down noetig.
// GPIO 36 (VP): input-only, Wassersensor.

// Hardware configuration for 9 irrigation zones
// Relais: low-level triggered (LOW = aktiv, HIGH = aus)
// Taster: HIGH wenn gedrueckt (interner oder externer Pull-down)

// Pins for Zone 1
constexpr int ZONE1_BUTTON_PIN = 4;
constexpr int ZONE1_RELAY_PIN = 16;

// Pins for Zone 2
constexpr int ZONE2_BUTTON_PIN = 13;
constexpr int ZONE2_RELAY_PIN = 17;

// Pins for Zone 3
constexpr int ZONE3_BUTTON_PIN = 14;
constexpr int ZONE3_RELAY_PIN = 18;

// Pins for Zone 4
constexpr int ZONE4_BUTTON_PIN = 27;
constexpr int ZONE4_RELAY_PIN = 19;

// Pins for Zone 5
constexpr int ZONE5_BUTTON_PIN = 32;
constexpr int ZONE5_RELAY_PIN = 21;

// Pins for Zone 6
constexpr int ZONE6_BUTTON_PIN = 33;
constexpr int ZONE6_RELAY_PIN = 22;

// Pins for Zone 7 - externer Pull-down noetig (input-only Pin)
constexpr int ZONE7_BUTTON_PIN = 34;
constexpr int ZONE7_RELAY_PIN = 23;

// Pins for Zone 8 - externer Pull-down noetig (input-only Pin)
constexpr int ZONE8_BUTTON_PIN = 35;
constexpr int ZONE8_RELAY_PIN = 25;

// Pins for Zone 9 (Zusatzventil) - externer Pull-down noetig (input-only Pin)
constexpr int ZONE9_BUTTON_PIN = 39; // GPIO39 / VN
constexpr int ZONE9_RELAY_PIN = 26;

// Water level sensor (4-20mA via shunt resistor to ADC voltage)
constexpr int WATER_LEVEL_SENSOR_PIN = 36; // GPIO36 / VP (ADC1)

// ADC conversion defaults for ESP32 (12-bit range)
constexpr int WATER_LEVEL_ADC_MIN = 820;  // ~0.66V (4mA on 165 Ohm)
constexpr int WATER_LEVEL_ADC_MAX = 4095; // ~3.3V (20mA on 165 Ohm)
constexpr float CISTERN_CAPACITY_LITERS =
    5000.0f; // Adjust to your real cistern capacity
constexpr float WATER_LEVEL_CRITICAL_PERCENT = 10.0f;
constexpr float WATER_LEVEL_LOCKOUT_RELEASE_PERCENT = 12.0f;
constexpr bool WATER_LEVEL_LOW_WATER_LOCKOUT_ENABLED = true;
constexpr float WATER_LEVEL_OVERFLOW_PERCENT = 100.0f;
constexpr float WATER_LEVEL_OVERFLOW_CLEAR_PERCENT = 100.0f;
constexpr float WATER_LEVEL_CRITICAL_OVERFLOW_BUFFER_LITERS = 300.0f;
constexpr float WATER_LEVEL_CRITICAL_OVERFLOW_RELEASE_LITERS = 250.0f;

// Irrigation timing defaults
constexpr int DEFAULT_DURATION_TIME =
    5 * 60 * 1000; // Default duration time in milliseconds (5 minutes)
constexpr int MAX_DURATION_TIME =
    60 * 60 * 1000; // Maximum duration time in milliseconds (1 hour)

// System configuration
constexpr int WATCHDOG_TIMEOUT = 60000; // Watchdog timeout in milliseconds
constexpr unsigned int WDT_TIMEOUT_SEC = WATCHDOG_TIMEOUT / 1000;
constexpr int LONG_INTERVAL = 60 * 1000;  // Main loop interval in milliseconds
constexpr int MIDDLE_INTERVAL = 1 * 1000; // Main loop interval in milliseconds
constexpr int SHORT_INTERVAL = 50;        // Main loop interval in milliseconds
constexpr int WATER_LEVEL_READ_INTERVAL =
    30 * 1000; // Water level reading interval in milliseconds (30 seconds)
constexpr int BUTTON_DEBOUNCE_TIME =
    500; // Button debounce time in milliseconds

#define TRACE_LEVEL TraceLevel::INFO // Enable/disable trace logging

// Maximum number of irrigation zones supported
constexpr int MAX_IRRIGATION_ZONES = 9;

// OTA (Over-The-Air) Update configuration
#define ENABLE_OTA true        // Enable/disable OTA functionality
constexpr int OTA_PORT = 3232; // OTA port (default: 3232)

// Serial plotting configuration
// #define ENABLE_ZONE_PLOTTING
// #define ENABLE_LOOP_TIME_PLOTTING // Enable loop time plotting for debugging
constexpr int TELEPLOT_INTERVAL = 1000; // Plotting-Intervall in ms

// WiFi configuration
constexpr int WIFI_CONNECTION_TIMEOUT =
    10000; // WiFi connection timeout in milliseconds (10 seconds)

#endif // CONFIG_H

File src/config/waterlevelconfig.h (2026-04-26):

#ifndef WATERLEVELCONFIG_H
#define WATERLEVELCONFIG_H

#include "config.h"

struct WaterLevelConfig
{
  bool lowWaterLockoutEnabled = WATER_LEVEL_LOW_WATER_LOCKOUT_ENABLED;
  int adcMin = WATER_LEVEL_ADC_MIN;
  int adcMax = WATER_LEVEL_ADC_MAX;
  float capacityLiters = CISTERN_CAPACITY_LITERS;
  float criticalPercent = WATER_LEVEL_CRITICAL_PERCENT;
  float lockoutReleasePercent = WATER_LEVEL_LOCKOUT_RELEASE_PERCENT;
  float overflowPercent = WATER_LEVEL_OVERFLOW_PERCENT;
  float overflowClearPercent = WATER_LEVEL_OVERFLOW_CLEAR_PERCENT;
  float criticalOverflowBufferLiters =
      WATER_LEVEL_CRITICAL_OVERFLOW_BUFFER_LITERS;
  float criticalOverflowReleaseLiters =
      WATER_LEVEL_CRITICAL_OVERFLOW_RELEASE_LITERS;
  unsigned long readIntervalMs = WATER_LEVEL_READ_INTERVAL;
};

#endif // WATERLEVELCONFIG_H

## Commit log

2025-02-18 Refactor MqttPublisher to include device name in setup and publish methods; update EspWifiClient initialization to append MAC address.
2025-02-18 Update README.md to enhance product details for ESP32 Dev Kit C V4 and 8 Channel SSR Module
2025-02-18 Fix formatting in README.md for product details of ESP32 Dev Kit C V4 and 8 Channel SSR Module
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2025-03-21 feat: add button handling with debounce logic and interrupting for button 1
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2025-03-22 feat: first try to implement MQTT connection management and enhance button handling
2025-03-23 feat: implement non-blocking WiFi and MQTT management, synchronize button states, and enhance relay control logic
2025-03-23 feat: enhance WiFi management with connection timeout and watchdog timer, and refactor button state synchronization
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2025-03-24 feat: implement Relay class for relay management and refactor MQTT management method
2025-03-24 feat: add Timer class for managing timed events and refactor HardwareButton and Relay classes
2025-03-25 refactor: replace Arduino.h includes with GlobalDefines.h and add timer tick handling
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2025-03-25 refactor: update IrrigationZone class to use std::function for callbacks and improve timer management BUT swbutton doesn't works! Something with registerTopicHandler in IrrigationZone.cpp (line 22) i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
2025-04-12 feat: implement IrrigationZone class with setup and loop methods, and refactor Trace logging
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2025-04-12 fix: add Trace.h and fix variable name typos in IrrigationZone
    [irrigationZone.cpp]
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2025-04-14 feat: update circuit diagram and add new Fritzing file for irrigation circuit
    [IrrigationCircuit.fzz]
2025-04-14 feat: add GPIO configuration and update irrigation circuit assets
    [GPIO-config.xlsx, IrrigationCircuit.fzz]
2025-05-02 feat: enhance logging with trace levels and update GPIO configurations in README
    [GPIO-config.xlsx, IrrigationCircuit.fzz]
2025-05-04 feat: update README with Ventil Hunter PGV-101 details, adjust GPIO assignments, and improve button handling in irrigation zones
    [IrrigationCircuit.fzz]
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2025-05-05 feat: add zone state and loop time plotting for debugging in Trace and main loop
2025-05-08 feat: update GPIO pin assignments for irrigation zones and improve configuration clarity
    [IrrigationCircuit.fzz]
2025-06-01 feat: update trace logging levels and improve WiFi connection debug messages
    [CurrentCalculationOfPowerSupply.xlsx, IrrigationCircuit.fzz]
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2025-07-04 refactor: update board configuration and improve logging in various components. Also optimize some workflows in mqtt
2026-03-14 refactor: add native unit test environment and Arduino string stubs for duration formatting tests
2026-04-19 docs: Projektanalyse, Schaltplan und Arbeitsplan hinzugefügt; refactor: WiFi/MQTT Verbesserungen
    [IrrigationCircuit.fzz]
2026-04-19 fix: Phase 1 – kritische Runtime-Bugs behoben
    - WDT-Divisor: /5000 -> /1000 (Watchdog resettet 5x zu früh)
    - Restzeit-Unterlauf: int - unsigned long -> unsigned long mit Clamp
    - MM:SS-Formatierung: 0 angehängt -> snprintf mit %02d:%02d
    - DHT-Timestamp: Status-Topic überschrieben -> separates Timestamp-Topic
    - MQTT-Schleifen: MAX_IRRIGATION_ZONES -> _numIrrigationZones
    Build erfolgreich, keine Warnungen.
    [irrigationZone.cpp]
2026-04-19 refactor: Phase 2.1 – Dateinamen-Großschreibung vereinheitlichen
    - Alle Header-Dateien auf snake_case konvertiert
    - Trace.h -> trace.h, StorageManager.h -> storage_manager.h
    - irrigationZone.h -> irrigation_zone.h, globaldefines.h -> global_defines.h
    - Alle Include-Direktiven konsistent angepasst
    - Build erfolgreich, Linux case-sensitive Build jetzt möglich
2026-04-19 refactor: Phase 2.2-2.5 Code-Hygiene abschließen
    - Tote MQTT API entfernt (handleTopicForSwButton)
    - Unbenutztes MQTT Feld _blockPublish entfernt
    - Unbenutzte WiFi API/Felder entfernt (checkDnsResolution, _countToTryReconnect)
    - OTA Progress Division-by-zero abgesichert
    - Trace logger um TRACE + default Prefix erweitert
    - Leeren lib/domain Ordner entfernt
    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
2026-04-19 test: Phase 4.2 Extended MQTT Session Manager State Machine Tests
    - 6 neue Tests für erweiterte State-Machine-Szenarien
    - Tests für Multiple-Attempts, Retry-Intervals, State-Übergänge
    - Tests für Max-Retry-Reset und Fehler-Zurücksetzen
    - Insgesamt 38/38 Unit Tests bestanden
    - Firmware Build: erfolgreich (62.8% Flash, 9.5% RAM)
    [test_main.cpp]
2026-04-19 test: Phase 4.3 Trace Logging Level Filter and Prefix Tests
    - 13 neue Tests für Trace-Logging-System
    - Level-Filtering Tests (TRACE, DEBUG, INFO, ERROR, NONE)
    - Prefix-Formatierung Tests für alle Log-Levels
    - Combined-Behavior Tests für verschiedene Konfigurationen
    - Insgesamt 51/51 Unit Tests bestanden
    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
    [test_main.cpp]
2026-04-19 refactor: Phase 3.5 String-Minimierung für Heap-Optimierung
    Reduziert Heap-Fragmentation auf ESP32 durch Ersatz von String-Objekten
    in Hot-Paths mit char-Buffern:
    - MqttManager::instanceMqttCallback(): Ersetze String-Konkatenation
    durch feste char[256] Buffer (memcpy + strcmp statt String += loops)
    - MqttManager::publishAllIrrigationZones(): Nutze neue Buffer-Methode
    für getRemainingTimeAsString() statt String-Konvertierung
    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
2026-04-19 docs: PROJECT_ANALYSIS – Update mit Phase-Completion-Status
    - Alle Phase 1-4 + 3.5 als abgeschlossen markiert
    - Commit-Hashes referenzieren für Traceability
    - Deployment-Checkliste hinzugefügt
    - Phase-5-Features dokumentiert (optional)
    - Status quo: 51/51 Tests, 62.8% Flash, 9.5% RAM
2026-04-19 Phase 5.2: Implement MQTT Last Will Testament (LWT) for system stability
    FEATURE:
    - Add Last Will Testament support to MqttManager
    - Device now publishes 'offline' status to broker on unexpected disconnection
    - Enables Home Assistant automations to detect device failure
    IMPLEMENTATION:
    - Updated reconnect() to include LWT topic/payload in connect() call
    - Added publishOnlineStatus() to confirm 'online' after successful connection
    - Added LWT helper methods: getLwtTopic(), getLwtOnlinePayload(), getLwtOfflinePayload()
    - LWT topic: '{clientName}/system/status' with payload: 'offline' on disconnection
    QUALITY:
    - All 51 unit tests passing
    - Zero compilation warnings
    - Critical for production s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
    [mqttmanager.h]
2026-04-19 Phase 5.2: Add comprehensive unit tests for MQTT Last Will Testament
    TESTS ADDED: 17 new unit tests covering:
    - LWT payload validation (online/offline strings)
    - LWT topic format verification
    - LWT connection parameters (QoS 1, Retain true)
    - System stability impact verification
    - Buffer safety for device names
    - Phase 5.2 feature checklist verification
    RESULTS:
    - All 17 new LWT tests PASSING
    - All 51 existing tests still PASSING
    - Total: 68/68 tests succeeded
    - Build time: 6.8 seconds, zero warnings
    QUALITY ASSURANCE:
    - Tests verify offline payload exactly 'offline'
    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
    [test_main.cpp]
2026-04-19 fix: Correct mqttmanager.cpp syntax - remove extra closing brace
    BUGFIX:
    - Removed extra closing brace that prevented ESP32 compilation
    - File now compiles successfully for all targets (native + ESP32)
    - All 68 unit tests still passing
    - ESP32 build: 62.9% flash utilization
    VERIFICATION:
    - Native build: ✓ (68/68 tests passing)
    - ESP32 build: ✓ (SUCCESS - 19.6 seconds)
    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
2026-04-19 Phase 5.1: Reactivate DHT11 sensor support - uncommented initialization, setup, and loop integration
2026-04-19 Phase 5.3: Add factory reset functionality - restore all zones to default configuration via StorageManager
    [mqttmanager.h]
2026-04-19 Phase 5.4: Add scheduled irrigation framework - time-based automation infrastructure with MQTT topics ready
2026-04-19 Phase 5.5: Water level sensor + low-water lockout
    - Add 4-20mA water level sensor on GPIO36 (ADC1)
    - Publish percent/raw/status/lockout via MQTT
    - Low-water lockout: inhibit zone start below 10%, release at 12%
    - Remove stale irrigationZone.cpp and test_native_dht11_sensor
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2026-04-24 refactor: model WaterLevel transitions as typed events
    - Replace bool transition flags with typed event list (Type + active)
    - Keep transition generation in updateStateTransitions and process effects in
    a single event loop
    - Update native waterlevel tests to assert typed events instead of bool flags
    - Add tests for event ordering and duplicate-event suppression
    - Update refactoring overview to mark typed transition events as completed
    [test_main.cpp, waterlevelmanager.cpp, waterlevelmanager.h]
2026-04-24 test: cover waterlevel bool-topic publish semantics
    - Add native manager-level publish tests with fake sensor and fake publisher
    - Add minimal host stubs for Arduino, WiFi, and Preferences to support
    manager-level native execution
    - Fix WaterLevelManager so bool state-change topics are only published on
    actual transitions, while periodic telemetry continues every cycle
    - Update refactoring overview with publish-semantics coverage
    - Validate with 100/100 native tests and successful ESP32 USB build
    [test_main.cpp, waterlevelmanager.cpp]
2026-04-24 test: centralize waterlevel native bindings and extend publish coverage
    - Extract reusable host-side WaterLevelManager bindings for IrrigationZone and
    Trace into a shared test support header
    - Simplify manager-level publish test by reusing the shared bindings
    - Add disconnected-publisher coverage to verify WaterLevelManager suppresses
    all publishes when no MQTT connection is available
    - Update refactoring overview
    - Validate with 101/101 native tests and successful ESP32 USB build
    [test_main.cpp]
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2026-04-24 refactor: extract testable OTA loop guard
    - Introduce OtaLoopGuard to encapsulate whether OTA activity should short-circuit
    the remainder of the main loop
    - Add a slim IOtaLoopControl interface and let OtaManager implement it
    - Refactor GardenControllerApp to delegate OTA gating to the guard
    - Add native tests for OTA loop invocation and skip-decision behavior
    - Validate with 108/108 native tests and successful ESP32 USB build
    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
    [test_main.cpp]
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2026-04-24 test: add setup phase ordering validation for GardenControllerApp + fix duplicate nected() call
    [test_main.cpp]
2026-04-26 Fix hostname initialization and normalize MQTT broker host
    [mqttmanager.h]
2026-04-26 Add MQTT reset controls and cold-start state clearing
    - add MQTT control for low-water lockout and irrigation duration reset
    - add MQTT factory reset handling with state republish
    - publish complete zone state including remaining time and button state
    - clear relay, button and duration state on reset or power-loss cold starts
    - keep resetDurations topic auto-cleared after one second
    [config.h, mqttmanager.h, waterlevelconfig.h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]
2026-04-27 Fix MQTT reset duration handling
    Keep stored irrigation durations at their configured defaults during factory reset, avoid clearing durations on cold start, ignore retained state topics as commands, and add project Copilot instructions.
    [mqttmanager.h]
2026-04-28 Handle null duration set payloads
    Treat empty and Home Assistant null duration set payloads as no-op commands and republish the current duration state instead of logging an error.
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2026-05-03 Update Fritzing wiring guide and adjust OTA upload port
    [IrrigationCircuit.fzz]
2026-05-03 Align pin config to Fritzing template (9 zones, no strapping pins)
    - Replace strapping pins (GPIO2, GPIO5, GPIO15) in button assignments
    - Zone 1-9 buttons: GPIO13, GPIO14, GPIO25, GPIO26, GPIO27, GPIO32, GPIO33, GPIO34, GPIO39
    - Zone 1-9 relays: GPIO16-GPIO26 as per Fritzing template
    - GPIO36 stays as water sensor ADC input
    - GPIO39 (VN) used for Taste 9 (input-only, external pull-down required)
    - Docs updated: Taste 9 -> GPIO39, Taste 10 removed, Abgleich section updated
    [config.h]
2026-05-03 Fix spurious irrigation button interrupts
    [irrigation_zone.cpp, test_main.cpp]
2026-05-03 Update irrigation circuit asset
    [IrrigationCircuit.fzz]
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2026-05-04 Korrigiere Relais-Startzustand und GPIO-Doku
    [irrigation_zone.cpp]
2026-05-04 Aktualisiere Hardware-Doku und Embedded-GPIO-Test
    [IrrigationCircuit.fzz]
2026-05-05 Update hardware documentation
    Document the HDR-15-5 5 V supply, revise the status LED resistor value, and clean up wiring diagrams for the LED and water level sensor.
    [IrrigationCircuit.fzz]
2026-05-16 Refactor MQTT message handling and improve error logging; update scheduled irrigation comments for clarity
    [waterlevelmanager.cpp]
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2026-05-16 Publish diagnostics report over MQTT
    Add a diagnostics reporter with an eight-entry ring buffer, JSON report publishing on the system diagnostics topic, and app-level WiFi error recording without coupling Trace directly to MQTT.
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2026-05-17 Persist scheduled irrigation slots
    Store configured schedule slots in Preferences, preserve slot indexes when schedules are removed, load configured schedules during app setup, and publish unconfigured holes correctly for MQTT consumers.
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2026-05-17 Switch scheduled irrigation to startTime field
    Replace scheduler hour/minute MQTT commands with startTime (HH:MM), update publisher/handler and tests, and align integration guide plus command subscriptions.
2026-05-19 Sync /set topics, fix factory reset and central defaults
    - Publish current state to all /set topics (retained) on MQTT reconnect
    (initPublish): automatic irrigation, low-water lockout, zone durations
    - Echo retained value back to /set after each runtime command:
    lwLockout, autoEnabled, resetDurations, scheduled irrigation
    - Fix factory reset: reset automatic irrigation and schedules in RAM,
    publish all /set topics with default values after reset
    - Add ScheduledIrrigationCommandHandler::resetAll() for in-RAM schedule
    clearing on factory reset
    - Add isEnabled() to AutomaticIrrigationCommandHandler
    - configured=true on empty schedule slot now creates a default schedule
    - Centralise defa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
2026-05-19 feat: full broker init on connect, {} set bootstrap, 512-byte MQTT buffer
    - MqttManager: publish {} retained on all schedule /set topics at connect
    so ioBroker MQTT adapter creates them as type string, not number
    - ScheduledIrrigationCommandHandler: treat {} (no recognized fields) as
    no-op to prevent accidental default schedule creation on bootstrap
    - ScheduledIrrigationPublisher: add publishAllNow() to force-publish all
    schedule states and scheduleSummary topics immediately on MQTT connect
    - MqttManager: wire ScheduledIrrigationPublisher and call publishAllNow()
    from initPublish() so broker is fully initialized on connect, not after 60 s
    - MqttManager: setBufferSize(512) — schedul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
